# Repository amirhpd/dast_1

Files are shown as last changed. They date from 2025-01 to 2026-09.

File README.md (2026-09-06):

# DAST-1

A serial manipulator: 3D-printed mechanics, hobby servos, an Arduino Nano 33 BLE Sense Rev2,
and a ROS 2 stack with MoveIt 2 motion planning and a Gazebo simulation.
The hardware has 5 joints; the simulated robot has a sixth, `joint_6`, a wrist rotation with no
servo behind it.

## Hardware

* Mechanical parts are 3D printed — printable STLs and drawings are in [`Mechanics/`](Mechanics),
  and the coordinate frames are shown in [`frames.pdf`](frames.pdf)
* 5 × MG996R servos, one per joint
* Controller: Arduino Nano 33 BLE Sense Rev2, connected over USB
* Firmware is in a separate project: [dast_1_emb](https://github.com/amirhpd/dast_1_emb)
* Xbox 360 Kinect (model 1414) for depth sensing — see [Kinect](#kinect) below

## Requirements

* Ubuntu 26.04 LTS with ROS 2 Lyrical Luth (Gazebo Jetty)

## Set up on a new machine

Everything needed to stand up a fresh machine lives in
[`system_mirroring/`](system_mirroring). Pick whichever route suits you.

### By hand

Four scripts, in order, then build:

```bash
git clone https://github.com/amirhpd/dast_1.git
cd dast_1/system_mirroring

./install_ros2_lyrical.sh                              # ROS 2 apt source + base system
./install_ros2_packages.sh                             # ROS/system packages + rosdep
pip install --user -r installed_python_packages.txt    # non-apt Python packages
./install_vscode_extensions.sh                         # VS Code (optional)

cd ..
source /opt/ros/lyrical/setup.bash
colcon build --cmake-args -DCMAKE_EXPORT_COMPILE_COMMANDS=ON
source install/setup.bash

./system_mirroring/verify_setup.sh                     # prints PASS/FAIL per item
```

A correct machine ends with `ALL CHECKS PASSED`.
[`system_mirroring.md`](system_mirroring/system_mirroring.md) explains each step
and the traps worth knowing about.

### With an AI agent

If you use Claude Code or a similar agent, clone the repo, open it, and paste
this prompt:

> Set this machine up to build and run the DAST-1 project.
>
> Follow `system_mirroring/system_mirroring.md` from the top. It targets Ubuntu
> 26.04 with ROS 2 Lyrical Luth — confirm the machine matches before you start,
> and stop and tell me if it does not.
>
> Run the four install scripts in order, then build the workspace with
> `colcon build --cmake-args -DCMAKE_EXPORT_COMPILE_COMMANDS=ON`, then run
> `system_mirroring/verify_setup.sh` and keep working until it reports
> `ALL CHECKS PASSED`.
>
> Notes:
> - `source /opt/ros/lyrical/setup.bash` and `source install/setup.bash` do not
>   survive between shell invocations — re-source them in every command.
> - The install scripts need `sudo` and will prompt. Tell me when you need me to
>   type a password rather than trying to work around it.
> - Finish with a headless smoke test:
>   `ros2 launch startup sim_robot.launch.py gui:=False rviz:=False`, then check
>   `ros2 control list_controllers` shows both controllers `active` and that
>   `ros2 action send_goal /task_server_angle msgs/action/TaskAction "task_number: 0"`
>   returns `success: true`. Do not open Gazebo or RViz windows.
> - Tear the sim down with a bracket pattern (`pkill -f "[g]z sim"`) — a plain
>   `pkill -f "gz sim"` also matches the shell running it.
> - Report anything you had to change from the documented steps, so I can fold it
>   back into `system_mirroring/`.

Hardware is not covered by any of the above. For the real robot, also add
yourself to the `dialout` group (`sudo usermod -aG dialout $USER`, then log out
and back in) and plug the Nano 33 into `/dev/ttyACM0`.

## Build

Once the machine is set up, a normal rebuild is:

```bash
cd dast_1
colcon build
source install/setup.bash
```

Run `source install/setup.bash` once in every new terminal. Add
`--cmake-args -DCMAKE_EXPORT_COMPILE_COMMANDS=ON` whenever you want editor
IntelliSense to pick up newly added includes.

## Run

Simulation — Gazebo, MoveIt and RViz, no hardware needed:

```bash
ros2 launch startup sim_robot.launch.py
```

Real robot — plug the Nano 33 in first (it is expected on `/dev/ttyACM0`):

```bash
ros2 launch startup run_robot.launch.py
```

Give it half a minute to settle. `ros2 control list_controllers` should show both
`joint_state_broadcaster` and `manipulator_controller` as `active`.

Everything below runs from a **second terminal**, sourced the same way
(`cd dast_1 && source install/setup.bash`).

### Moving the arm

There are two families of commands. The first plans through MoveIt: motions are checked
against obstacles and the arm takes a safe route. The second talks straight to the
controller: faster and simpler, but nothing is checked before the arm moves.

#### Through MoveIt — collision-checked

**Drag it in RViz.** In the **MotionPlanning** panel, drag the goal marker to where you
want the tip, then press *Plan & Execute*.

**Run a stored task.** Three canned poses ship with the project, numbered 0, 1 and 2:

```bash
ros2 action send_goal /task_server_angle msgs/action/TaskAction "task_number: 1"
```

**Set the joint angles** — five values, in **degrees**, one per joint:

```bash
ros2 run moveit interface_angle 20 30 -15 40 10
```

**Set the tip pose** — `x y z roll pitch yaw`, in **metres and radians**:

```bash
ros2 run moveit interface_pose 1.173 -3.223 6.196 0.953 -0.143 0.450
```

Not every pose is reachable; see *Reachable workspace* below. To find a valid one, move the
arm with `interface_angle` and read the tip off `ros2 run tf2_ros tf2_echo world tip`.

**Follow a trajectory of several waypoints.** The waypoints live in a YAML file, and the
whole path is planned segment by segment:

```bash
ros2 run moveit interface_sequence src/moveit/config/sequence_example.yaml
```

Copy `src/moveit/config/sequence_example.yaml` and edit its `segments:` list to make your
own path. Each segment takes either `joints:` (radians) or `pose:`, and the file's comments
explain the rest. Leave `blend_radius: 0` — corner-rounding needs a 6-DOF arm and DAST-1
has 5, so any other value fails the whole sequence.

#### Straight to the controller — no collision checking

These bypass MoveIt entirely. Nothing stops the arm driving through an obstacle, or through
itself, so keep the workspace clear.

**Send one trajectory and forget it.** Positions are in **radians**, in `joint_names` order:

```bash
ros2 topic pub --once /manipulator_controller/joint_trajectory trajectory_msgs/msg/JointTrajectory \
'{joint_names: [joint_1, joint_2, joint_3, joint_4, joint_5],
  points: [{positions: [0.3, 0.4, -0.2, 0.5, 0.1], time_from_start: {sec: 3}}]}'
```

**Send it and wait for the result.** Same thing as an action, so you get success or failure
back, and `--feedback` will stream progress while it runs:

```bash
ros2 action send_goal /manipulator_controller/follow_joint_trajectory \
  control_msgs/action/FollowJointTrajectory \
'{trajectory: {joint_names: [joint_1, joint_2, joint_3, joint_4, joint_5],
  points: [{positions: [0.4, 0.2, 0.3, 0.5, 0.0], time_from_start: {sec: 2}},
           {positions: [-0.4, 0.6, 0.1, 1.0, 0.2], time_from_start: {sec: 5}}]}}'
```

`time_from_start` counts from the beginning of the trajectory, so each waypoint's value must
be larger than the one before it.

### Reachable workspace

All joints are limited to ±90°, and not every pose in that range can be reached.
The scan sweeps `joint_1`..`joint_5` with `joint_6` held at 0, so it understates the
reachable workspace of the 6-DOF description.
`points.pcd` holds the measured reachable workspace:

```bash
ros2 run moveit publish_pointcloud.py     # run from the repository root
```

It publishes to `/point_cloud`; add a **PointCloud2** display in RViz to see it.

## Kinect

An Xbox 360 Kinect (model 1414) provides colour and depth. It is driven by the `kinect`
package, which is **standalone**: it is not started by `sim_robot.launch.py` or
`run_robot.launch.py`, and nothing in the robot stack depends on it yet.

It needs its 12 V power brick as well as USB. On USB alone only the motor enumerates and the
LED blinks green — `lsusb | grep 045e` must list all three of `02b0` (motor), `02ad` (audio)
and `02ae` (camera).

```bash
ros2 launch kinect kinect.launch.py              # driver + static TF
ros2 launch kinect kinect.launch.py rviz:=True   # ...and RViz, preconfigured
```

| topic | type | contents |
| --- | --- | --- |
| `/kinect/rgb/image_raw` | `sensor_msgs/Image` | `rgb8`, 640×480, 30 Hz |
| `/kinect/depth/image_raw` | `sensor_msgs/Image` | `16UC1`, millimetres, 0 where nothing was seen |
| `/kinect/points` | `sensor_msgs/PointCloud2` | organised XYZRGB, one point per pixel |
| `/kinect/rgb/camera_info`, `/kinect/depth/camera_info` | `sensor_msgs/CameraInfo` | the calibration below |

Depth is captured as `FREENECT_DEPTH_REGISTERED`, so it is already aligned to the colour image
and one calibration covers both. The point cloud is only built while something is subscribed to
it — it is about 4.9 MB per frame.

### Calibration

The measured intrinsics for this unit live in
[`src/kinect/config/kinect_rgb.yaml`](src/kinect/config/kinect_rgb.yaml) and are loaded at
startup through the `camera_info_url` parameter
(default `package://kinect/config/kinect_rgb.yaml`). Editing that file and restarting is
enough — no rebuild. If the file is missing or is not 640×480, the node warns and falls back to
nominal Kinect v1 values, and the cloud becomes approximate.

| | |
| --- | --- |
| fx, fy | 549.996, 552.698 |
| cx, cy | 316.370, 269.456 |
| distortion (`plumb_bob`) | 0.168766, −0.361444, 0.002809, −0.002889, 0 |

Distortion is corrected when the cloud is built, through a per-pixel lookup table computed once
at startup. It is not a small effect: at 1 m depth it moves a corner pixel by about 4 cm.

To redo the calibration — 8×6 interior corners, 25 mm squares:

```bash
ros2 launch kinect kinect.launch.py
ros2 run camera_calibration cameracalibrator --size 8x6 --square 0.025 \
  --no-service-check --ros-args \
  -r image:=/kinect/rgb/image_raw -r camera:=/kinect/rgb
```

Two upstream bugs in `camera_calibration` 7.1.7 have to be patched first, or it crashes on
startup and again on SAVE. Both are one-line fixes to installed files, and an `apt upgrade`
silently reverts them:

```bash
sudo sed -i 's/self\.get_logger()\.warn(/self.get_logger().warning(/' \
  /opt/ros/lyrical/lib/python3.14/site-packages/camera_calibration/camera_calibrator.py
sudo sed -i 's/\.tostring()/.tobytes()/' \
  /opt/ros/lyrical/lib/python3.14/site-packages/camera_calibration/mono_calibrator.py \
  /opt/ros/lyrical/lib/python3.14/site-packages/camera_calibration/stereo_calibrator.py
```

### Where to bolt it

Two measured limits decide the mounting position.

**Minimum range is about 50 cm.** The closest reading over 900 frames was 502 mm, and nothing
nearer than that exists. Anything closer is reported as 0, which becomes a *hole* in the point
cloud — and a hole reads as empty space to MoveIt, not as an obstacle. Mount the camera so the
whole arm workspace stays beyond roughly 60 cm.

**The field of view is 60.4° × 46.9°**, computed from the intrinsics above:

| distance | area covered |
| --- | --- |
| 0.6 m | 0.70 × 0.52 m |
| 1.0 m | 1.16 × 0.87 m |
| 1.5 m | 1.75 × 1.30 m |
| 2.0 m | 2.33 × 1.74 m |

The arm reaches about 0.71 m (`points.pcd` measures 7.14 model units, and the model is in
decimetres — see *Units* below), so an eye-to-hand mount around 1 m back covers the workspace and
stays clear of the 50 cm floor. The current mount is 1.03 m from `base_link`.

Depth noise, measured as the per-pixel standard deviation over 30 s:

| range | median σ | 95th percentile |
| --- | --- | --- |
| 0.5–0.7 m | 0.5 mm | 0.7 mm |
| 0.9–1.1 m | 1.4 mm | 2.2 mm |
| 1.4–1.8 m | 2.8 mm | 4.6 mm |

A 1 cm octomap voxel is therefore comfortable out to about 2 m. Over the same 30 s the driver
delivered 899 frames at 29.97 Hz with no drops, and the Kinect had its internal USB hub to
itself; the Nano's serial traffic is negligible beside it.

**Tilt.** The Kinect's motorised base holds whatever angle it was last commanded to, and forgets
it when the 12 V drops. The driver therefore commands the tilt on every start, so it is the same
angle every run rather than whatever someone last left it at:

```bash
ros2 launch kinect kinect.launch.py tilt_degrees:=-16   # -30..30, negative is head down
```

The default is **−16°**, matching the current mount. After moving the motor the node reads the
angle back from the accelerometer and warns if it does not match what was commanded — a stalled
motor is otherwise invisible. Set `set_tilt:=False` to leave the motor untouched.

> The tilt must match the angle the camera-to-`base_link` transform was measured at. Change
> `tilt_degrees` and every extrinsic is silently wrong, with nothing to show for it but a point
> cloud that no longer lines up with the robot. Repeatability is about 1°, so bake the nominal
> tilt into the URDF as well.

### In the robot

The camera is part of the robot description, so both modes publish the same topics and the
planner sees the same obstacles:

| | simulation | real robot |
| --- | --- | --- |
| source | Gazebo `rgbd_camera` + `ros_gz_bridge` | `kinect_node` |
| started by | `sim_robot.launch.py` | `run_robot.launch.py` |
| `/kinect/points` | ✔ | ✔ |
| `/kinect/rgb/image_raw` | ✔ | ✔ |
| `/kinect/depth/image_raw` | `32FC1`, model units | `16UC1`, millimetres |
| `/kinect/depth/camera_info` | — | ✔ |
| cloud `frame_id` | `kinect_link` (x forward) | `kinect_rgb_optical_frame` (z forward) |

The last two rows are the only differences. Gazebo emits its cloud along the sensor link's **x**
axis and `gz_frame_id` only labels the message rather than rotating it, so the simulated cloud is
published in `kinect_link` and the real one in the optical frame. Both are correct in their own
frame and TF reconciles them, so RViz and MoveIt behave identically — but code that hardcodes a
frame name instead of asking TF will only work in one mode.

The mount pose lives in `description.urdf.xacro` as `kinect_xyz` / `kinect_rpy`, and
`sensors_3d.yaml` feeds `/kinect/points` to MoveIt's octomap at a 1 cm voxel.

Gazebo needs `worlds/dast_1.sdf` rather than its stock `empty.sdf`: the stock world does not load
`gz-sim-sensors-system`, and without it the camera is created and advertises every topic but
never renders a frame, silently.

### Units

**The robot model is in decimetres, not metres.** The meshes are millimetres scaled by `0.01`, so
one unit in the URDF is 10 cm: the 8 cm printed base is `0.8`, the 0.71 m reach is `7.14`, and
`points.pcd` spans ±5.8. Every length in the URDF, `sensors_3d.yaml` and the Gazebo sensor
follows that convention.

The Kinect does not. Its driver publishes true metres, so `run_robot.launch.py` passes
`point_scale: 10.0` to convert the cloud into model units. Simulation needs no such conversion —
Gazebo already works in whatever units the URDF uses.

This is worth fixing properly one day, by scaling the meshes at `0.001` and dividing every joint
origin by ten. That would also invalidate every recorded pose, `points.pcd` and the waypoint
YAMLs, so it is deliberately not done here.

### Checking the sensor

Depth and geometry come from different places, so they fail differently:

* `z` comes straight from the Kinect's own factory depth calibration and is passed through
  untouched. Check it against a tape measure on a flat wall. Expect a 1–2 cm offset, because the
  depth origin sits inside the housing rather than at the front glass — measure at two distances
  and compare the *difference*, which cancels the offset.
* `x` and `y` come from the intrinsics above. Check them against a known width: hold a ruler
  flat, facing the camera, add a **PointCloud2** display in RViz, pick the **Select** tool, box
  a few points at each end, and read `Position → x` under each point in the **Selection** panel.
  Values are in metres. Expand the `Point ...` rows — the number in the row itself is only an
  index.

## License

This project is licensed under the GPLv3 License.

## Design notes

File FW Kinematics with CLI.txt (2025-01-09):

FW kinematics:

ros2 launch description display.launch.py

ros2 topic list 
gives: /tf which is dynamic transformation and /tf_static which is static transformation

ros2 topic info /tf --verbose
we see that robot_state_publisher node is publishing to /tf

ros2 topic eccho /tf
it constantly publishes the msgs that define the position of each frame relative to the previous frame

ros2 run tf2_tools view_frames
generates a graph of the frames and their connections

ros2 run tf2_ros tf2_echo world tip
gives translation and rotation values of between the given frames
if the first and last frames are passed, it actually solves the fw kinematics problem

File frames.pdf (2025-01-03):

view_frames Result

Recorded at time: 1735861924.2365034

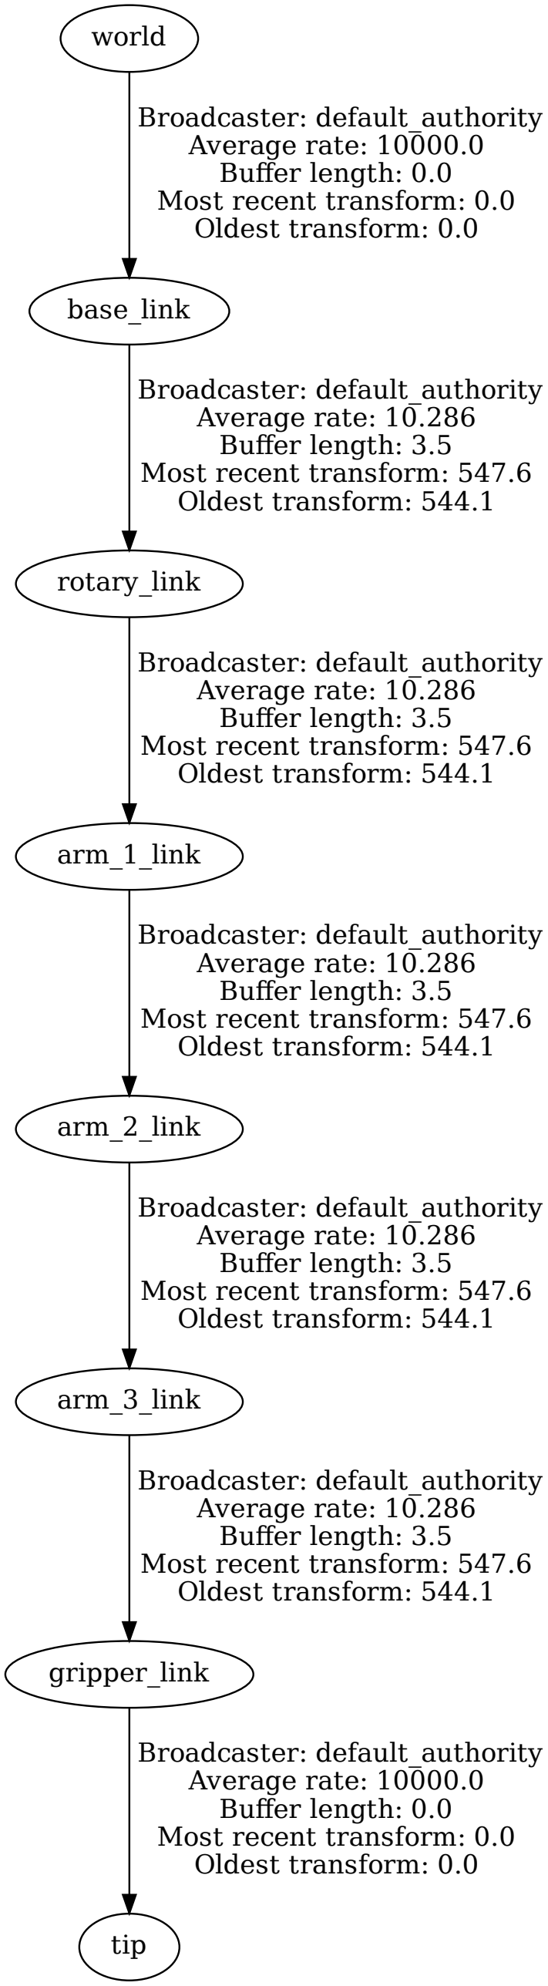
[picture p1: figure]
world; base_link; Broadcaster: default_authority Average rate: 10000.0 Buffer length: 0.0 Most recent transform: 0.0 Oldest transform: 0.0; rotary_link; Broadcaster: default_authority Average rate: 10.286 Buffer length: 3.5 Most recent transform: 547.6 Oldest transform: 544.1; gripper_link; tip; arm_3_link; arm_1_link; arm_2_link

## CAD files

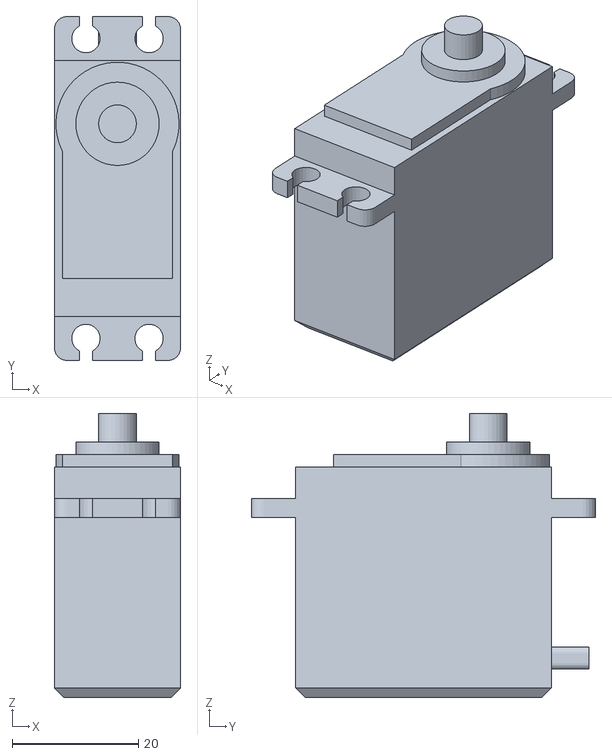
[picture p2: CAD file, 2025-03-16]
Mechanics/ARM-1/servo_mg996r.stl
20.0 x 54.5 x 45.0

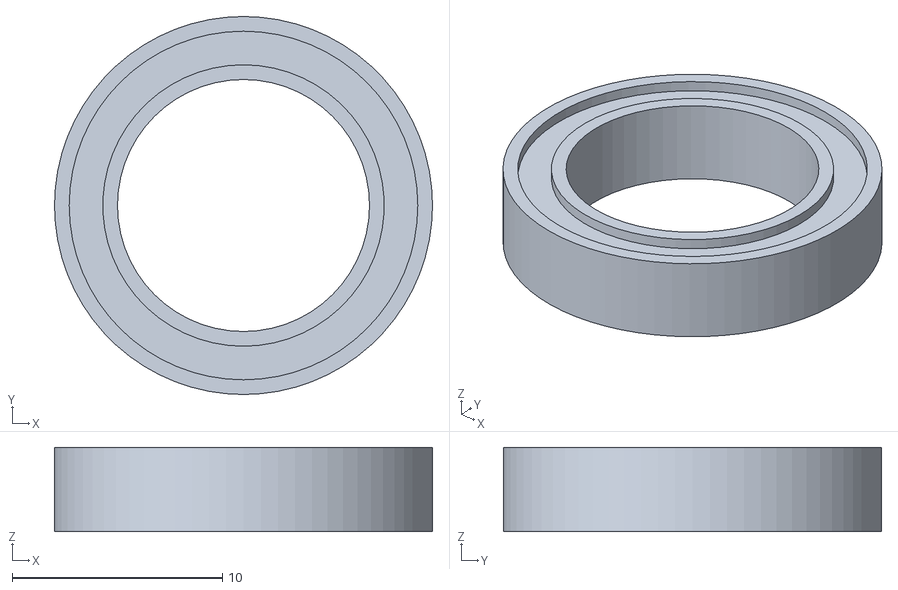
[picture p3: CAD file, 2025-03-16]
Mechanics/BASE/bearing_18_12_4.stl
18.0 x 18.0 x 4.00

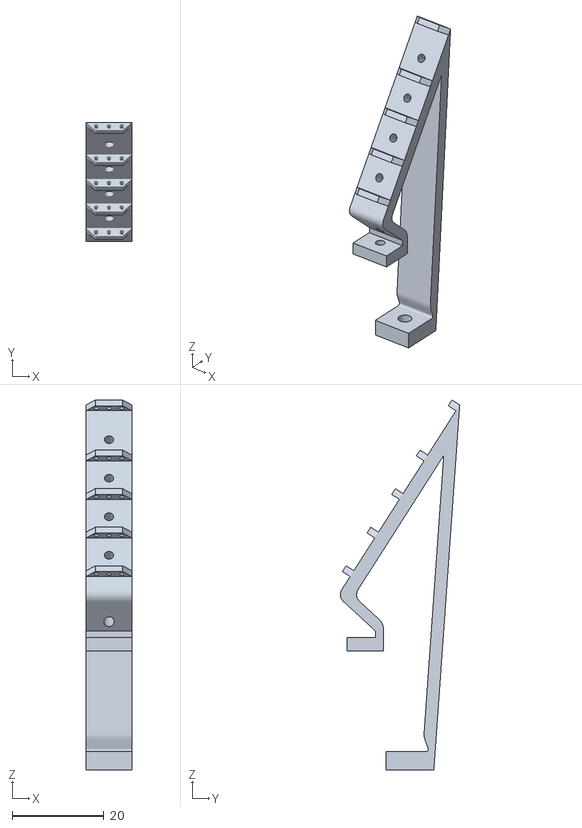
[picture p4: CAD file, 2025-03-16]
Mechanics/GRIPPER/finger_8.stl
10.00 x 26.1 x 80.9

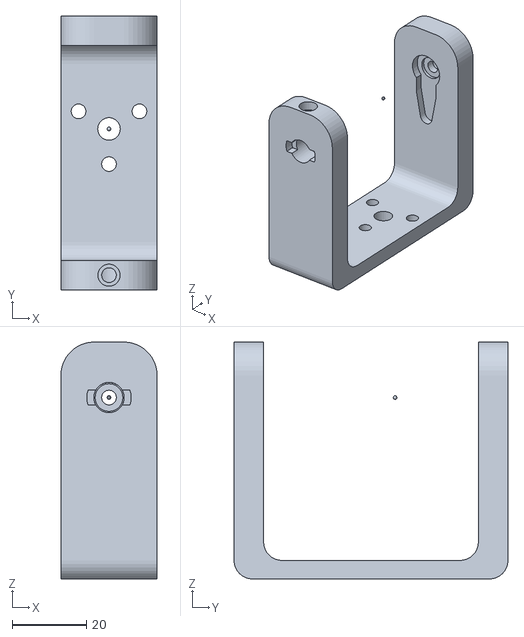
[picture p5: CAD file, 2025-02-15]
src/description/meshes/rotary.stl
26.0 x 74.0 x 64.0

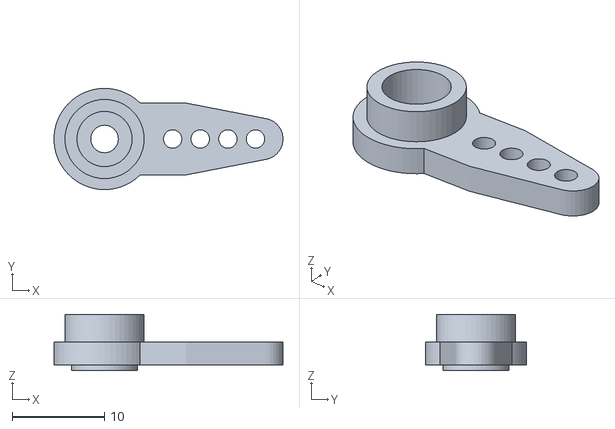
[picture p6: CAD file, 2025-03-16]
Mechanics/ARM-1/servo_connector_3.stl
24.9 x 11.0 x 6.10

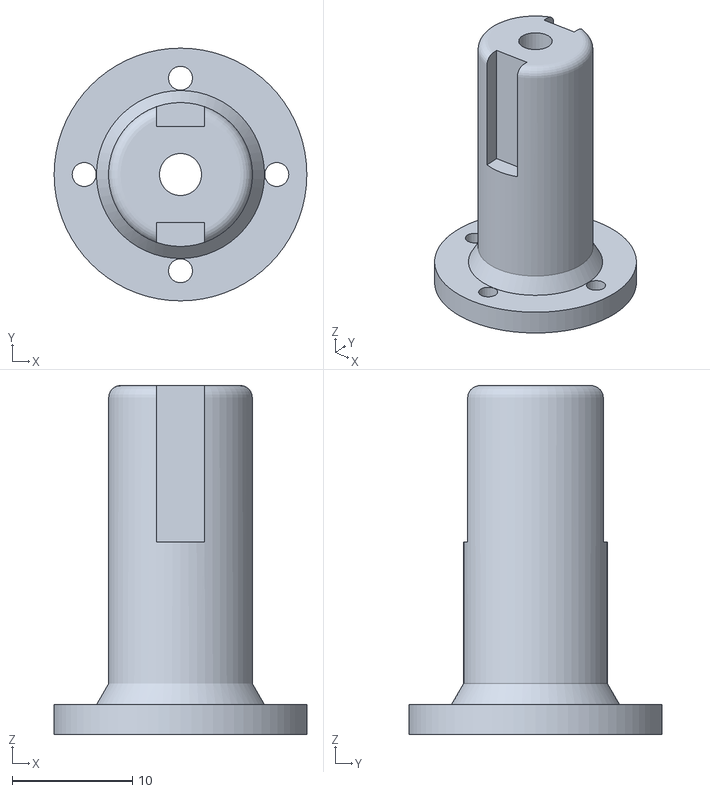
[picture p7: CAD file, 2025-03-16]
Mechanics/ARM-3/joint_5_shaft.stl
21.0 x 21.0 x 29.0

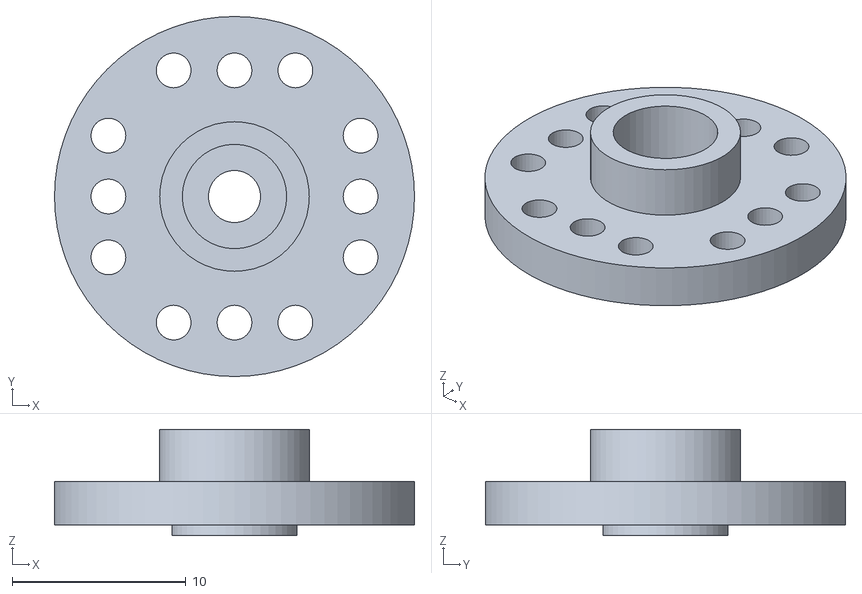
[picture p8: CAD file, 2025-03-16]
Mechanics/BASE/servo_connector_1.stl
20.7 x 20.7 x 6.10

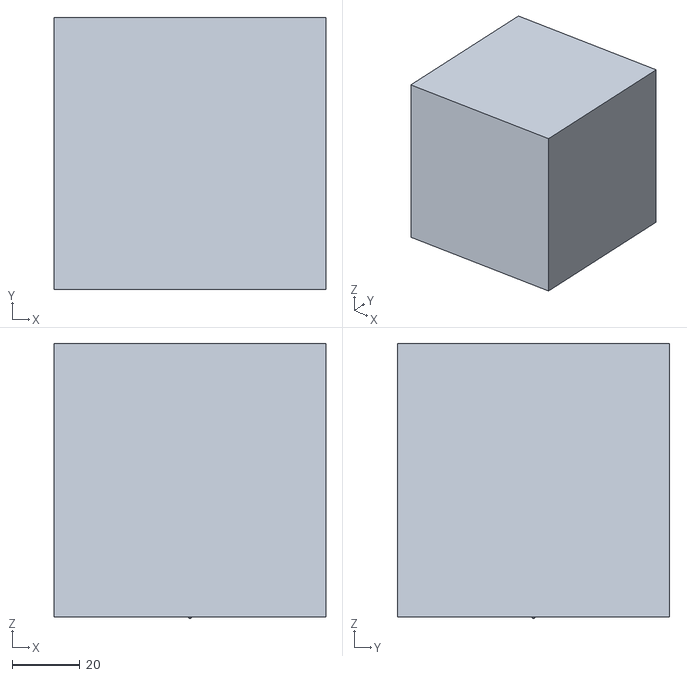
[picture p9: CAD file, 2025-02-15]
src/description/meshes/base_collision.stl
80.5 x 80.5 x 81.5

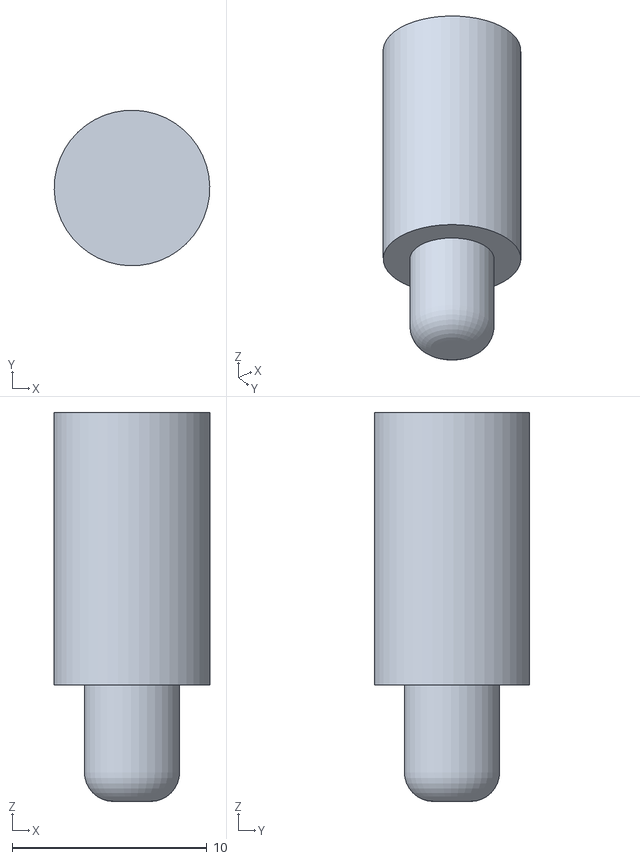
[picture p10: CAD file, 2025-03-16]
Mechanics/ARM-1/bearing_shaft.stl
8.00 x 7.99 x 20.0

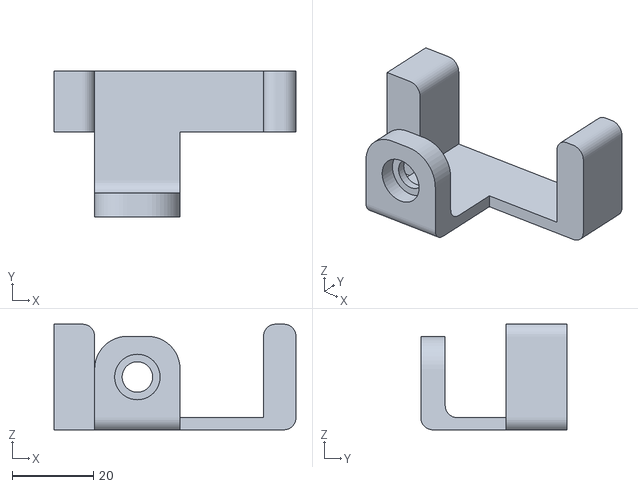
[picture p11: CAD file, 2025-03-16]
Mechanics/ARM-3/arm_3_body.stl
59.5 x 36.0 x 26.0

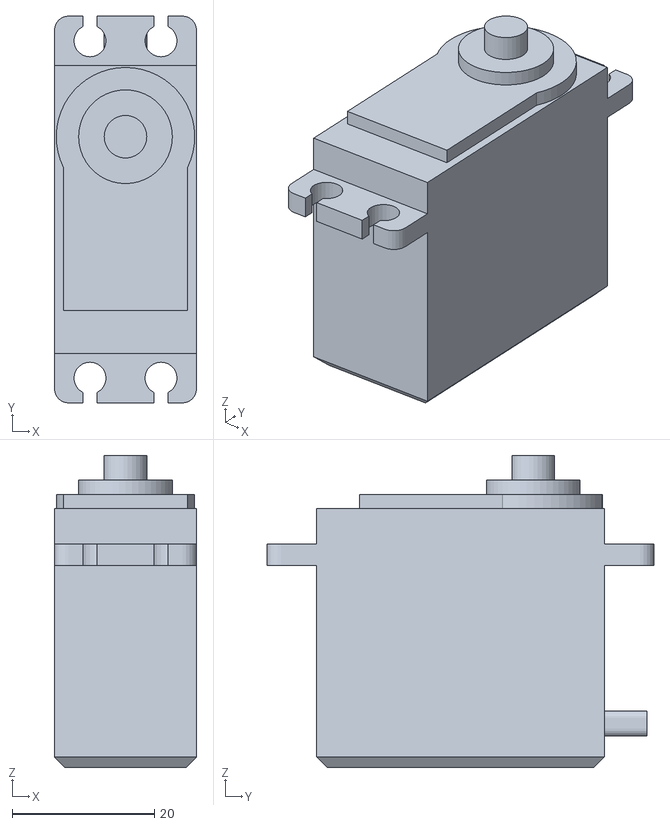
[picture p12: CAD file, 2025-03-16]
Mechanics/BASE/servo_mg996r.stl
20.0 x 54.5 x 44.0

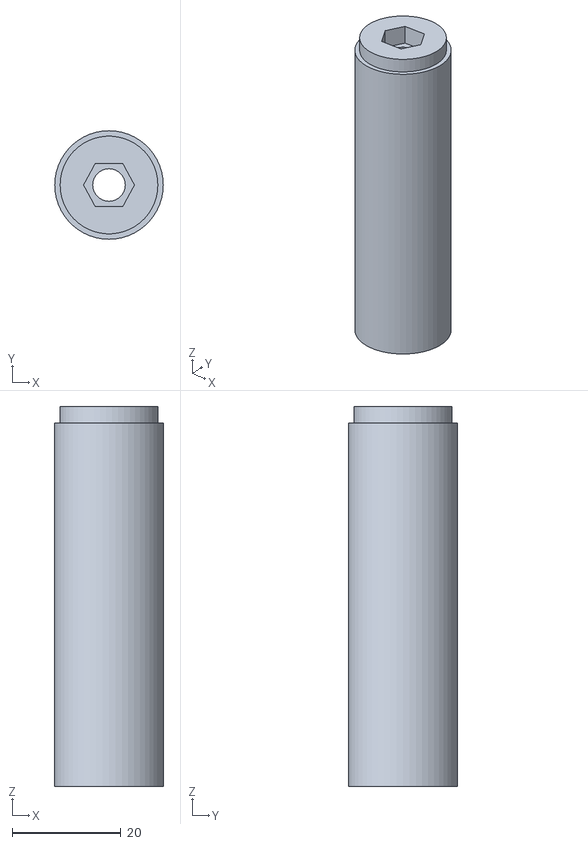
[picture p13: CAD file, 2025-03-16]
Mechanics/GRIPPER/motor_hold.stl
20.0 x 20.0 x 70.0

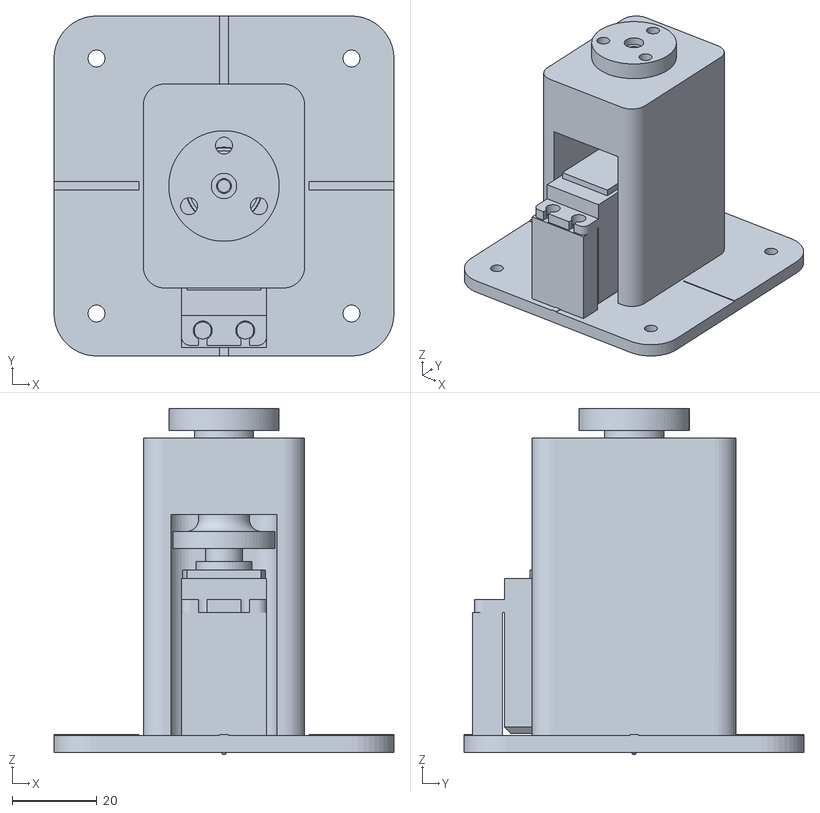
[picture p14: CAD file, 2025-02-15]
src/description/meshes/base.stl
80.0 x 80.0 x 81.5

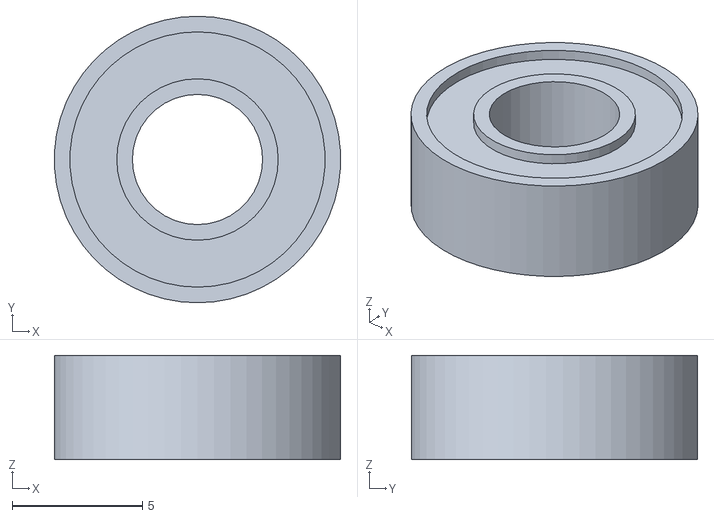
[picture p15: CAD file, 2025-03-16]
Mechanics/ARM-1/bearing_11_5_4.stl
11.0 x 11.0 x 4.00

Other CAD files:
Mechanics/ARM-2/joint_2_housing.stl
Mechanics/ARM-1/arm_1_body.stl
Mechanics/ARM-1/joint_1_housing.stl
Mechanics/ARM-2/arm_2_body.stl
Mechanics/ARM-3/joint_3_housing.stl
Mechanics/ARM-3/joint_5_body.stl
Mechanics/BASE/housing.stl
Mechanics/BASE/plate.stl
Mechanics/BASE/shaft.stl
Mechanics/BASE/shaft_hold.stl
Mechanics/GRIPPER/body.stl
Mechanics/GRIPPER/bolt_cap.stl
Mechanics/GRIPPER/coupling.stl
Mechanics/GRIPPER/motor_1.stl
Mechanics/GRIPPER/screw.stl
Mechanics/GRIPPER/screw_head.stl
src/description/meshes/arm_1.stl
src/description/meshes/arm_1_collision.stl
src/description/meshes/arm_2.stl
src/description/meshes/arm_2_collision.stl
src/description/meshes/arm_3.stl
src/description/meshes/arm_3_collision.stl
src/description/meshes/gripper_3.stl
src/description/meshes/gripper_3_collision.stl
src/description/meshes/rotary_collision.stl

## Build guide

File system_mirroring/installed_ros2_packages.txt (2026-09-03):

libserial-dev
ros-dev-tools
ros-lyrical-desktop
ros-lyrical-gz-ros2-control
ros-lyrical-joint-state-publisher-gui
ros-lyrical-moveit
ros-lyrical-moveit-planners
ros-lyrical-pcl-conversions
ros-lyrical-pcl-ros
ros-lyrical-ros2-control
ros-lyrical-ros2-controllers
ros-lyrical-ros-gz-bridge
ros-lyrical-ros-gz-sim
ros-lyrical-xacro

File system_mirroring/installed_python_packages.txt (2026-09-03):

# Python packages the project needs that do NOT come from apt.
#
# Everything else it imports -- numpy, pyserial, and all rclpy/launch/moveit
# modules -- arrives with the ros-lyrical-* apt packages. Do NOT pip-install
# ROS Python modules; they must match the apt build exactly.
#
# Ubuntu 26.04 is an externally-managed Python environment (PEP 668), so pip
# needs --user (or a venv). Install with:
#     pip install --user -r installed_python_packages.txt

pypcd4>=1.4.3

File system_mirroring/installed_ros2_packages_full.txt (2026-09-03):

ros-lyrical-ackermann-msgs=2.0.2-7resolute.20260811.214511
ros-lyrical-ackermann-steering-controller=6.9.0-1resolute.20260813.022148
ros-lyrical-action-msgs=2.4.5-1resolute.20260811.210253
ros-lyrical-action-tutorials-cpp=0.37.9-1resolute.20260812.021114
ros-lyrical-action-tutorials-py=0.37.9-1resolute.20260812.021218
ros-lyrical-actuator-msgs=0.0.1-5resolute.20260811.214520
ros-lyrical-admittance-controller=6.9.0-1resolute.20260813.021833
ros-lyrical-ament-cmake=2.8.8-1resolute.20260728.175713
ros-lyrical-ament-cmake-auto=2.8.8-1resolute.20260728.210738
ros-lyrical-ament-cmake-copyright=0.20.6-1resolute.20260728.204014
ros-lyrical-ament-cmake-core=2.8.8-1resolute.20260728.162608
ros-lyrical-ament-cmake-cppcheck=0.20.6-1resolute.20260728.204151
ros-lyrical-ament-cmake-cpplint=0.20.6-1resolute.20260728.204159
ros-lyrical-ament-cmake-export-definitions=2.8.8-1resolute.20260728.173325
ros-lyrical-ament-cmake-export-dependencies=2.8.8-1resolute.20260728.173500
ros-lyrical-ament-cmake-export-include-directories=2.8.8-1resolute.20260728.172444
ros-lyrical-ament-cmake-export-libraries=2.8.8-1resolute.20260728.173328
ros-lyrical-ament-cmake-export-link-flags=2.8.8-1resolute.20260728.173334
ros-lyrical-ament-cmake-export-targets=2.8.8-1resolute.20260728.173432
ros-lyrical-ament-cmake-flake8=0.20.6-1resolute.20260728.204007
ros-lyrical-ament-cmake-gen-version-h=2.8.8-1resolute.20260728.173325
ros-lyrical-ament-cmake-gmock=2.8.8-1resolute.20260728.175747
ros-lyrical-ament-cmake-gtest=2.8.8-1resolute.20260728.175609
ros-lyrical-ament-cmake-include-directories=2.8.8-1resolute.20260728.173227
ros-lyrical-ament-cmake-libraries=2.8.8-1resolute.20260728.173352
ros-lyrical-ament-cmake-lint-cmake=0.20.6-1resolute.20260728.204241
ros-lyrical-ament-cmake-mypy=0.20.6-1resolute.20260728.204152
ros-lyrical-ament-cmake-pep257=0.20.6-1resolute.20260728.204012
ros-lyrical-ament-cmake-pytest=2.8.8-1resolute.20260728.175653
ros-lyrical-ament-cmake-python=2.8.8-1resolute.20260728.173021
ros-lyrical-ament-cmake-ros=0.15.8-1resolute.20260812.003148
ros-lyrical-ament-cmake-ros-core=0.15.8-1resolute.20260728.173607
ros-lyrical-ament-cmake-target-dependencies=2.8.8-1resolute.20260728.173503
ros-lyrical-ament-cmake-test=2.8.8-1resolute.20260728.175319
ros-lyrical-ament-cmake-uncrustify=0.20.6-1resolute.20260728.210813
ros-lyrical-ament-cmake-version=2.8.8-1resolute.20260728.173013
ros-lyrical-ament-cmake-xmllint=0.20.6-1resolute.20260728.204019
ros-lyrical-ament-copyright=0.20.6-1resolute.20260728.172704
ros-lyrical-ament-cppcheck=0.20.6-1resolute.20260728.173125
ros-lyrical-ament-cpplint=0.20.6-1resolute.20260728.173508
ros-lyrical-ament-flake8=0.20.6-1resolute.20260728.172702
ros-lyrical-ament-index-cpp=1.13.3-3resolute.20260728.204744
ros-lyrical-ament-index-python=1.13.3-3resolute.20260728.172618
ros-lyrical-ament-lint=0.20.6-1resolute.20260728.172451
ros-lyrical-ament-lint-auto=0.20.6-1resolute.20260728.204247
ros-lyrical-ament-lint-cmake=0.20.6-1resolute.20260728.173508
ros-lyrical-ament-lint-common=0.20.6-1resolute.20260728.211054
ros-lyrical-ament-mypy=0.20.6-1resolute.20260728.173532
ros-lyrical-ament-package=0.18.3-3resolute.20260430.010336
ros-lyrical-ament-pep257=0.20.6-1resolute.20260728.172706
ros-lyrical-ament-uncrustify=0.20.6-1resolute.20260728.210701
ros-lyrical-ament-xmllint=0.20.6-1resolute.20260728.172708
ros-lyrical-angles=1.16.1-3resolute.20260728.204755
ros-lyrical-backward-ros=1.0.8-5resolute.20260728.173605
ros-lyrical-battery-state-broadcaster=6.9.0-1resolute.20260813.021523
ros-lyrical-bicycle-steering-controller=6.9.0-1resolute.20260813.022055
ros-lyrical-builtin-interfaces=2.4.5-1resolute.20260811.194455
ros-lyrical-chained-filter-controller=6.9.0-1resolute.20260813.021545
ros-lyrical-chomp-motion-planner=2.15.0-1resolute.20260814.183552
ros-lyrical-class-loader=2.9.4-3resolute.20260728.211940
ros-lyrical-common-interfaces=5.9.3-1resolute.20260811.235041
ros-lyrical-composition=0.37.9-1resolute.20260812.024540
ros-lyrical-composition-interfaces=2.4.5-1resolute.20260811.235637
ros-lyrical-console-bridge-vendor=1.9.1-3resolute.20260728.205113
ros-lyrical-controller-interface=6.9.0-1resolute.20260812.031044
ros-lyrical-controller-manager=6.9.0-1resolute.20260812.031837
ros-lyrical-controller-manager-msgs=6.9.0-1resolute.20260811.235011
ros-lyrical-control-msgs=6.10.0-1resolute.20260812.000019
ros-lyrical-control-toolbox=6.4.0-1resolute.20260813.020756
ros-lyrical-cv-bridge=4.1.0-3resolute.20260812.021420
ros-lyrical-demo-nodes-cpp=0.37.9-1resolute.20260812.024338
ros-lyrical-demo-nodes-cpp-native=0.37.9-1resolute.20260812.021113
ros-lyrical-demo-nodes-py=0.37.9-1resolute.20260812.023921
ros-lyrical-depthimage-to-laserscan=2.5.1-4resolute.20260812.021437
ros-lyrical-desktop=0.13.0-3resolute.20260812.081153
ros-lyrical-diagnostic-msgs=5.9.3-1resolute.20260811.231430
ros-lyrical-diagnostic-updater=4.4.7-1resolute.20260812.015047
ros-lyrical-diff-drive-controller=6.9.0-1resolute.20260813.021810
ros-lyrical-dummy-map-server=0.37.9-1resolute.20260812.021337
ros-lyrical-dummy-robot-bringup=0.37.9-1resolute.20260812.080900
ros-lyrical-dummy-sensors=0.37.9-1resolute.20260812.021451
ros-lyrical-eigen3-cmake-module=0.5.1-3resolute.20260728.205221
ros-lyrical-eigen-stl-containers=1.1.0-3resolute.20260728.205309
ros-lyrical-example-interfaces=0.14.1-3resolute.20260811.214647
ros-lyrical-examples-rclcpp-minimal-action-client=0.21.5-3resolute.20260812.021115
ros-lyrical-examples-rclcpp-minimal-action-server=0.21.5-3resolute.20260812.021127
ros-lyrical-examples-rclcpp-minimal-client=0.21.5-3resolute.20260812.021143
ros-lyrical-examples-rclcpp-minimal-composition=0.21.5-3resolute.20260812.015758
ros-lyrical-examples-rclcpp-minimal-publisher=0.21.5-3resolute.20260812.015042
ros-lyrical-examples-rclcpp-minimal-service=0.21.5-3resolute.20260812.021144
ros-lyrical-examples-rclcpp-minimal-subscriber=0.21.5-3resolute.20260812.015803
ros-lyrical-examples-rclcpp-minimal-timer=0.21.5-3resolute.20260812.023244
ros-lyrical-examples-rclcpp-multithreaded-executor=0.21.5-3resolute.20260812.015114
ros-lyrical-examples-rclpy-executors=0.21.5-3resolute.20260812.023800
ros-lyrical-examples-rclpy-minimal-action-client=0.21.5-3resolute.20260812.023832
ros-lyrical-examples-rclpy-minimal-action-server=0.21.5-3resolute.20260812.021220
ros-lyrical-examples-rclpy-minimal-client=0.21.5-3resolute.20260812.023835
ros-lyrical-examples-rclpy-minimal-publisher=0.21.5-3resolute.20260812.024013
ros-lyrical-examples-rclpy-minimal-service=0.21.5-3resolute.20260812.024002
ros-lyrical-examples-rclpy-minimal-subscriber=0.21.5-3resolute.20260812.024040
ros-lyrical-fastcdr=2.3.6-1resolute.20260728.172850
ros-lyrical-fastdds=3.6.2-1resolute.20260728.174239
ros-lyrical-filters=2.2.2-3resolute.20260812.023251
ros-lyrical-foonathan-memory-vendor=1.4.1-1resolute.20260728.173726
ros-lyrical-force-torque-sensor-broadcaster=6.9.0-1resolute.20260813.020931
ros-lyrical-forward-command-controller=6.9.0-1resolute.20260813.021543
ros-lyrical-generate-parameter-library=1.3.0-1resolute.20260812.024534
ros-lyrical-generate-parameter-library-py=1.3.0-1resolute.20260728.174510
ros-lyrical-geometric-shapes=2.3.4-1resolute.20260812.014934
ros-lyrical-geometry2=0.45.9-1resolute.20260812.065932
ros-lyrical-geometry-msgs=5.9.3-1resolute.20260811.214840
ros-lyrical-google-benchmark-vendor=0.7.0-3resolute.20260728.170214
ros-lyrical-gpio-controllers=6.9.0-1resolute.20260813.020932
ros-lyrical-gps-msgs=3.1.1-1resolute.20260817.165952
ros-lyrical-gps-sensor-broadcaster=6.9.0-1resolute.20260813.021543
ros-lyrical-gz-cmake-vendor=0.4.5-1resolute.20260728.204248
ros-lyrical-gz-common-vendor=0.3.6-1resolute.20260728.211925
ros-lyrical-gz-dartsim-vendor=0.1.3-3resolute.20260728.205412
ros-lyrical-gz-fuel-tools-vendor=0.3.1-3resolute.20260728.213226
ros-lyrical-gz-gui-vendor=0.3.1-3resolute.20260729.165027
ros-lyrical-gz-math-vendor=0.4.4-1resolute.20260728.210836
ros-lyrical-gz-msgs-vendor=0.3.4-2resolute.20260728.211937
ros-lyrical-gz-ogre-next-vendor=0.2.1-1resolute.20260728.205418
ros-lyrical-gz-physics-vendor=0.4.5-1resolute.20260728.230022
ros-lyrical-gz-plugin-vendor=0.3.1-3resolute.20260728.210826
ros-lyrical-gz-rendering-vendor=0.4.4-1resolute.20260729.162653
ros-lyrical-gz-ros2-control=3.0.8-1resolute.20260812.033512
ros-lyrical-gz-sensors-vendor=0.3.3-1resolute.20260729.170045
ros-lyrical-gz-sim-vendor=0.4.6-1resolute.20260810.125655
ros-lyrical-gz-tools-vendor=0.2.1-3resolute.20260728.204537
ros-lyrical-gz-transport-vendor=0.3.5-1resolute.20260728.213714
ros-lyrical-gz-utils-vendor=0.4.1-3resolute.20260728.210531
ros-lyrical-hardware-interface=6.9.0-1resolute.20260812.025059
ros-lyrical-image-geometry=4.1.0-3resolute.20260812.010916
ros-lyrical-image-tools=0.37.9-1resolute.20260812.015825
ros-lyrical-image-transport=6.4.10-1resolute.20260812.021512
ros-lyrical-imu-sensor-broadcaster=6.9.0-1resolute.20260813.020929
ros-lyrical-interactive-markers=2.8.4-1resolute.20260812.025722
ros-lyrical-intra-process-demo=0.37.9-1resolute.20260812.020838
ros-lyrical-joint-limits=6.9.0-1resolute.20260812.024530
ros-lyrical-joint-state-broadcaster=6.9.0-1resolute.20260813.021535
ros-lyrical-joint-state-publisher=2.4.3-1resolute.20260812.024103
ros-lyrical-joint-state-publisher-gui=2.4.3-1resolute.20260812.024521
ros-lyrical-joint-trajectory-controller=6.9.0-1resolute.20260813.021739
ros-lyrical-joy=3.3.0-4resolute.20260812.021518
ros-lyrical-kdl-parser=3.0.1-3resolute.20260812.012108
ros-lyrical-keyboard-handler=0.5.1-1resolute.20260728.205547
ros-lyrical-kinematics-interface=2.4.2-1resolute.20260812.023544
ros-lyrical-laser-geometry=2.11.3-6resolute.20260812.065336
ros-lyrical-launch=3.9.8-1resolute.20260728.172811
ros-lyrical-launch-param-builder=0.1.1-5resolute.20260812.022149
ros-lyrical-launch-ros=0.29.9-1resolute.20260812.024129
ros-lyrical-launch-testing=3.9.8-1resolute.20260728.175423
ros-lyrical-launch-testing-ament-cmake=3.9.8-1resolute.20260728.205136
ros-lyrical-launch-testing-ros=0.29.9-1resolute.20260812.024517
ros-lyrical-launch-xml=3.9.8-1resolute.20260728.175211
ros-lyrical-launch-yaml=3.9.8-1resolute.20260728.172929
ros-lyrical-libstatistics-collector=2.1.2-1resolute.20260812.012738
ros-lyrical-libyaml-vendor=1.8.1-3resolute.20260728.205613
ros-lyrical-lifecycle=0.37.9-1resolute.20260812.015506
ros-lyrical-lifecycle-msgs=2.4.5-1resolute.20260811.234650
ros-lyrical-logging-demo=0.37.9-1resolute.20260812.015543
ros-lyrical-lz4-cmake-module=0.33.3-1resolute.20260728.205656
ros-lyrical-magnetometer-broadcaster=6.9.0-1resolute.20260813.021541
ros-lyrical-map-msgs=2.6.1-1resolute.20260811.234335
ros-lyrical-marine-acoustic-msgs=2.1.0-3resolute.20260811.233749
ros-lyrical-mcap-vendor=0.33.3-1resolute.20260728.210724
ros-lyrical-mecanum-drive-controller=6.9.0-1resolute.20260813.021811
ros-lyrical-message-filters=7.4.2-1resolute.20260812.014855
ros-lyrical-motion-primitives-controllers=6.9.0-1resolute.20260813.020935
ros-lyrical-moveit=2.15.0-1resolute.20260814.213024
ros-lyrical-moveit-common=2.15.0-1resolute.20260813.020940
ros-lyrical-moveit-configs-utils=2.15.0-1resolute.20260813.021545
ros-lyrical-moveit-core=2.15.0-1resolute.20260814.181429
ros-lyrical-moveit-kinematics=2.15.0-1resolute.20260814.194910
ros-lyrical-moveit-msgs=2.7.2-1resolute.20260814.175542
ros-lyrical-moveit-planners=2.15.0-1resolute.20260814.201908
ros-lyrical-moveit-planners-chomp=2.15.0-1resolute.20260814.184504
ros-lyrical-moveit-planners-ompl=2.15.0-1resolute.20260814.195244
ros-lyrical-moveit-planners-stomp=2.15.0-1resolute.20260814.183549
ros-lyrical-moveit-plugins=2.15.0-1resolute.20260814.184435
ros-lyrical-moveit-ros=2.15.0-1resolute.20260814.204723
ros-lyrical-moveit-ros-benchmarks=2.15.0-1resolute.20260814.201408
ros-lyrical-moveit-ros-move-group=2.15.0-1resolute.20260814.195128
ros-lyrical-moveit-ros-occupancy-map-monitor=2.15.0-1resolute.20260814.185343
ros-lyrical-moveit-ros-planning=2.15.0-1resolute.20260814.192648
ros-lyrical-moveit-ros-planning-interface=2.15.0-1resolute.20260814.201720
ros-lyrical-moveit-ros-robot-interaction=2.15.0-1resolute.20260814.194810
ros-lyrical-moveit-ros-visualization=2.15.0-1resolute.20260814.202013
ros-lyrical-moveit-ros-warehouse=2.15.0-1resolute.20260814.195656
ros-lyrical-moveit-setup-app-plugins=2.15.0-1resolute.20260814.210341
ros-lyrical-moveit-setup-assistant=2.15.0-1resolute.20260814.212621
ros-lyrical-moveit-setup-controllers=2.15.0-1resolute.20260814.210341
ros-lyrical-moveit-setup-core-plugins=2.15.0-1resolute.20260814.210607
ros-lyrical-moveit-setup-framework=2.15.0-1resolute.20260814.210017
ros-lyrical-moveit-setup-srdf-plugins=2.15.0-1resolute.20260814.210346
ros-lyrical-moveit-simple-controller-manager=2.15.0-1resolute.20260814.183549
ros-lyrical-nav-msgs=5.9.3-1resolute.20260811.232935
ros-lyrical-object-recognition-msgs=2.0.0-6resolute.20260811.234429
ros-lyrical-octomap-msgs=2.0.1-3resolute.20260811.233803
ros-lyrical-omni-wheel-drive-controller=6.9.0-1resolute.20260813.021006
ros-lyrical-ompl=2.0.1-3resolute.20260728.173004
ros-lyrical-orocos-kdl-vendor=0.8.0-3resolute.20260728.205531
ros-lyrical-osqp-vendor=1.0.0-1resolute.20260811.125853
ros-lyrical-pal-statistics=2.8.0-1resolute.20260812.020510
ros-lyrical-pal-statistics-msgs=2.8.0-1resolute.20260811.215029
ros-lyrical-parallel-gripper-controller=6.9.0-1resolute.20260813.021750
ros-lyrical-pcl-conversions=2.10.0-1resolute.20260812.065431
ros-lyrical-pcl-msgs=1.0.0-10resolute.20260812.064641
ros-lyrical-pcl-ros=2.10.0-1resolute.20260812.070823
ros-lyrical-pendulum-control=0.37.9-1resolute.20260812.015613
ros-lyrical-pendulum-msgs=0.37.9-1resolute.20260811.234822
ros-lyrical-pid-controller=6.9.0-1resolute.20260813.021755
ros-lyrical-pilz-industrial-motion-planner=2.15.0-1resolute.20260814.200329
ros-lyrical-pluginlib=5.8.4-3resolute.20260728.212925
ros-lyrical-point-cloud-transport=5.4.3-1resolute.20260812.021543
ros-lyrical-pose-broadcaster=6.9.0-1resolute.20260813.021008
ros-lyrical-python-qt-binding=2.5.5-1resolute.20260728.205956
ros-lyrical-qt-dotgraph=2.11.1-1resolute.20260728.210436
ros-lyrical-qt-gui=2.11.1-1resolute.20260728.210439
ros-lyrical-qt-gui-cpp=2.11.1-1resolute.20260728.213227
ros-lyrical-qt-gui-py-common=2.11.1-1resolute.20260728.210443
ros-lyrical-quality-of-service-demo-cpp=0.37.9-1resolute.20260812.024540
ros-lyrical-quality-of-service-demo-py=0.37.9-1resolute.20260812.021217
ros-lyrical-random-numbers=2.0.5-1resolute.20260728.210002
ros-lyrical-range-sensor-broadcaster=6.9.0-1resolute.20260813.021034
ros-lyrical-rcl=10.4.4-1resolute.20260812.012321
ros-lyrical-rcl-action=10.4.4-1resolute.20260812.012801
ros-lyrical-rclcpp=32.0.2-1resolute.20260812.014037
ros-lyrical-rclcpp-action=32.0.2-1resolute.20260812.014919
ros-lyrical-rclcpp-components=32.0.2-1resolute.20260812.015019
ros-lyrical-rclcpp-lifecycle=32.0.2-1resolute.20260812.014952
ros-lyrical-rcl-interfaces=2.4.5-1resolute.20260811.234851
ros-lyrical-rcl-lifecycle=10.4.4-1resolute.20260812.012718
ros-lyrical-rcl-logging-implementation=3.4.1-3resolute.20260812.011632
ros-lyrical-rcl-logging-interface=3.4.1-3resolute.20260812.010932
ros-lyrical-rcl-logging-spdlog=3.4.1-3resolute.20260812.011255
ros-lyrical-rclpy=10.0.10-1resolute.20260812.014024
ros-lyrical-rcl-yaml-param-parser=10.4.4-1resolute.20260812.010939
ros-lyrical-rcpputils=2.14.5-1resolute.20260728.210316
ros-lyrical-rcutils=7.1.2-1resolute.20260728.210016
ros-lyrical-realtime-tools=5.2.0-3resolute.20260812.023617
ros-lyrical-resource-retriever=3.9.3-3resolute.20260812.010941
ros-lyrical-resource-retriever-interfaces=0.0.3-1resolute.20260811.215055
ros-lyrical-resource-retriever-service-plugin=0.0.3-1resolute.20260812.015310
ros-lyrical-rmw=7.10.1-5resolute.20260728.210946
ros-lyrical-rmw-dds-common=6.0.0-3resolute.20260811.214453
ros-lyrical-rmw-fastrtps-cpp=9.4.9-1resolute.20260812.000633
ros-lyrical-rmw-fastrtps-shared-cpp=9.4.9-1resolute.20260811.235827
ros-lyrical-rmw-implementation=3.1.6-1resolute.20260812.001853
ros-lyrical-rmw-implementation-cmake=7.10.1-5resolute.20260728.210014
ros-lyrical-rmw-security-common=7.10.1-5resolute.20260728.211356
ros-lyrical-rmw-test-fixture=0.15.8-1resolute.20260728.211417
ros-lyrical-rmw-test-fixture-implementation=0.15.8-1resolute.20260812.002527
ros-lyrical-robot-state-publisher=3.5.5-3resolute.20260812.020221
ros-lyrical-ros2action=0.40.8-1resolute.20260812.022257
ros-lyrical-ros2bag=0.33.3-1resolute.20260812.034142
ros-lyrical-ros2cli=0.40.8-1resolute.20260812.022130
ros-lyrical-ros2cli-common-extensions=0.5.2-3resolute.20260812.025525
ros-lyrical-ros2component=0.40.8-1resolute.20260812.025106
ros-lyrical-ros2-control=6.9.0-1resolute.20260812.034329
ros-lyrical-ros2controlcli=6.9.0-1resolute.20260812.032651
ros-lyrical-ros2-control-cmake=0.3.0-3resolute.20260728.210022
ros-lyrical-ros2-controllers=6.9.0-1resolute.20260813.022832
ros-lyrical-ros2-control-test-assets=6.9.0-1resolute.20260810.231204
ros-lyrical-ros2doctor=0.40.8-1resolute.20260812.022413
ros-lyrical-ros2interface=0.40.8-1resolute.20260812.024852
ros-lyrical-ros2launch=0.29.9-1resolute.20260812.025115
ros-lyrical-ros2lifecycle=0.40.8-1resolute.20260812.023056
ros-lyrical-ros2multicast=0.40.8-1resolute.20260812.024851
ros-lyrical-ros2node=0.40.8-1resolute.20260812.022937
ros-lyrical-ros2param=0.40.8-1resolute.20260812.023104
ros-lyrical-ros2pkg=0.40.8-1resolute.20260812.024906
ros-lyrical-ros2plugin=5.8.4-3resolute.20260812.025108
ros-lyrical-ros2run=0.40.8-1resolute.20260812.025152
ros-lyrical-ros2service=0.40.8-1resolute.20260812.022915
ros-lyrical-ros2topic=0.40.8-1resolute.20260812.022955
ros-lyrical-rosbag2=0.33.3-1resolute.20260812.034437
ros-lyrical-rosbag2-compression=0.33.3-1resolute.20260812.031247
ros-lyrical-rosbag2-compression-zstd=0.33.3-1resolute.20260812.033924
ros-lyrical-rosbag2-cpp=0.33.3-1resolute.20260812.024604
ros-lyrical-rosbag2-interfaces=0.33.3-1resolute.20260811.213023
ros-lyrical-rosbag2-py=0.33.3-1resolute.20260812.033351
ros-lyrical-rosbag2-storage=0.33.3-1resolute.20260812.023725
ros-lyrical-rosbag2-storage-default-plugins=0.33.3-1resolute.20260812.033812
ros-lyrical-rosbag2-storage-mcap=0.33.3-1resolute.20260812.031353
ros-lyrical-rosbag2-storage-sqlite3=0.33.3-1resolute.20260812.031643
ros-lyrical-rosbag2-transport=0.33.3-1resolute.20260812.031909
ros-lyrical-ros-base=0.13.0-3resolute.20260812.070046
ros-lyrical-ros-core=0.13.0-3resolute.20260812.025814
ros-lyrical-ros-environment=4.5.1-1resolute.20260728.172811
ros-lyrical-rosgraph-msgs=2.4.5-1resolute.20260811.235432
ros-lyrical-ros-gz-bridge=3.0.9-1resolute.20260817.170928
ros-lyrical-ros-gz-interfaces=3.0.9-1resolute.20260811.235421
ros-lyrical-ros-gz-sim=3.0.9-1resolute.20260812.025049
ros-lyrical-rosidl-adapter=5.2.1-1resolute.20260728.204010
ros-lyrical-rosidl-buffer=5.2.1-1resolute.20260728.210115
ros-lyrical-rosidl-buffer-backend=5.2.1-1resolute.20260728.211422
ros-lyrical-rosidl-buffer-backend-registry=5.2.1-1resolute.20260728.213234
ros-lyrical-rosidl-buffer-py=5.2.1-1resolute.20260728.210209
ros-lyrical-rosidl-cli=5.2.1-1resolute.20260728.173046
ros-lyrical-rosidl-cmake=5.2.1-1resolute.20260728.210427
ros-lyrical-rosidl-core-generators=0.4.3-3resolute.20260811.194301
ros-lyrical-rosidl-core-runtime=0.4.3-3resolute.20260728.212309
ros-lyrical-rosidl-default-generators=1.8.1-3resolute.20260811.211639
ros-lyrical-rosidl-default-runtime=1.8.1-3resolute.20260811.210711
ros-lyrical-rosidl-dynamic-typesupport=0.4.1-3resolute.20260728.210642
ros-lyrical-rosidl-dynamic-typesupport-fastrtps=0.5.1-3resolute.20260728.210954
ros-lyrical-rosidl-generator-c=5.2.1-1resolute.20260728.210700
ros-lyrical-rosidl-generator-cpp=5.2.1-1resolute.20260728.210943
ros-lyrical-rosidl-generator-py=0.27.2-3resolute.20260728.211553
ros-lyrical-rosidl-generator-rs=0.5.0-2resolute.20260811.194003
ros-lyrical-rosidl-generator-type-description=5.2.1-1resolute.20260728.210206
ros-lyrical-rosidl-parser=5.2.1-1resolute.20260728.210114
ros-lyrical-rosidl-pycommon=5.2.1-1resolute.20260728.210228
ros-lyrical-rosidl-runtime-c=5.2.1-1resolute.20260728.210328
ros-lyrical-rosidl-runtime-cpp=5.2.1-1resolute.20260728.210648
ros-lyrical-rosidl-runtime-py=0.15.2-3resolute.20260728.210536
ros-lyrical-rosidl-typesupport-c=3.4.2-3resolute.20260728.211303
ros-lyrical-rosidl-typesupport-cpp=3.4.2-3resolute.20260728.211628
ros-lyrical-rosidl-typesupport-fastrtps-c=3.9.5-3resolute.20260728.211956
ros-lyrical-rosidl-typesupport-fastrtps-cpp=3.9.5-3resolute.20260728.211709
ros-lyrical-rosidl-typesupport-interface=5.2.1-1resolute.20260728.210128
ros-lyrical-rosidl-typesupport-introspection-c=5.2.1-1resolute.20260728.210952
ros-lyrical-rosidl-typesupport-introspection-cpp=5.2.1-1resolute.20260728.211325
ros-lyrical-ros-workspace=1.0.3-9resolute.20260728.162902
ros-lyrical-rpyutils=0.7.2-3resolute.20260728.174949
ros-lyrical-rqt-action=2.5.0-1resolute.20260812.025524
ros-lyrical-rqt-bag=2.2.5-1resolute.20260812.034206
ros-lyrical-rqt-bag-plugins=2.2.5-1resolute.20260812.034656
ros-lyrical-rqt-common-plugins=1.2.0-5resolute.20260812.034821
ros-lyrical-rqt-console=2.4.4-1resolute.20260812.023325
ros-lyrical-rqt-graph=1.8.5-1resolute.20260812.023457
ros-lyrical-rqt-gui=1.10.6-1resolute.20260812.022147
ros-lyrical-rqt-gui-cpp=1.10.6-1resolute.20260812.023746
ros-lyrical-rqt-gui-py=1.10.6-1resolute.20260812.023155
ros-lyrical-rqt-image-view=2.0.5-3resolute.20260812.024710
ros-lyrical-rqt-msg=1.7.4-1resolute.20260812.023530
ros-lyrical-rqt-plot=1.7.6-1resolute.20260812.023316
ros-lyrical-rqt-publisher=1.10.4-1resolute.20260812.023431
ros-lyrical-rqt-py-common=1.10.6-1resolute.20260812.022236
ros-lyrical-rqt-py-console=1.5.3-1resolute.20260812.023448
ros-lyrical-rqt-reconfigure=1.8.6-1resolute.20260812.023511
ros-lyrical-rqt-service-caller=1.5.4-1resolute.20260812.025639
ros-lyrical-rqt-shell=1.4.2-1resolute.20260812.025614
ros-lyrical-rqt-srv=1.4.1-3resolute.20260812.025549
ros-lyrical-rqt-topic=2.1.2-1resolute.20260812.023437
ros-lyrical-rsl=1.3.0-3resolute.20260812.023757
ros-lyrical-rttest=0.20.1-1resolute.20260728.210200
ros-lyrical-ruckig=0.9.2-6resolute.20260728.172957
ros-lyrical-rviz2=15.2.5-1resolute.20260812.080038
ros-lyrical-rviz-common=15.2.5-1resolute.20260812.020303
ros-lyrical-rviz-default-plugins=15.2.5-1resolute.20260812.065920
ros-lyrical-rviz-ogre-vendor=15.2.5-1resolute.20260728.210151
ros-lyrical-rviz-rendering=15.2.5-1resolute.20260812.011315
ros-lyrical-sdformat-urdf=2.1.1-1resolute.20260812.012055
ros-lyrical-sdformat-vendor=0.3.4-1resolute.20260728.211924
ros-lyrical-sdl2-vendor=3.3.0-4resolute.20260728.210149
ros-lyrical-sensor-msgs=5.9.3-1resolute.20260811.233053
ros-lyrical-sensor-msgs-py=5.9.3-1resolute.20260812.064948
ros-lyrical-service-msgs=2.4.5-1resolute.20260811.200407
ros-lyrical-shape-msgs=5.9.3-1resolute.20260811.233816
ros-lyrical-simulation-interfaces=2.1.0-3resolute.20260811.233050
ros-lyrical-spdlog-vendor=1.8.0-3resolute.20260728.210243
ros-lyrical-srdfdom=2.0.9-3resolute.20260812.022759
ros-lyrical-sros2=0.16.6-1resolute.20260812.023125
ros-lyrical-sros2-cmake=0.16.6-1resolute.20260812.024945
ros-lyrical-state-interfaces-broadcaster=6.9.0-1resolute.20260813.021331
ros-lyrical-statistics-msgs=2.4.5-1resolute.20260811.213037
ros-lyrical-std-msgs=5.9.3-1resolute.20260811.213219
ros-lyrical-std-srvs=5.9.3-1resolute.20260811.234022
ros-lyrical-steering-controllers-library=6.9.0-1resolute.20260813.021509
ros-lyrical-stereo-msgs=5.9.3-1resolute.20260811.234335
ros-lyrical-stomp=0.1.2-5resolute.20260728.173012
ros-lyrical-tango-icons-vendor=0.5.1-3resolute.20260728.210308
ros-lyrical-tcb-span=2.0.3-1resolute.20260728.210330
ros-lyrical-teleop-twist-joy=2.6.5-3resolute.20260812.022254
ros-lyrical-teleop-twist-keyboard=2.4.1-3resolute.20260812.024553
ros-lyrical-tf2=0.45.9-1resolute.20260812.011045
ros-lyrical-tf2-bullet=0.45.9-1resolute.20260812.020722
ros-lyrical-tf2-eigen=0.45.9-1resolute.20260812.020513
ros-lyrical-tf2-eigen-kdl=0.45.9-1resolute.20260812.011952
ros-lyrical-tf2-geometry-msgs=0.45.9-1resolute.20260812.025229
ros-lyrical-tf2-kdl=0.45.9-1resolute.20260812.025208
ros-lyrical-tf2-msgs=0.45.9-1resolute.20260811.233056
ros-lyrical-tf2-py=0.45.9-1resolute.20260812.024611
ros-lyrical-tf2-ros=0.45.9-1resolute.20260812.015530
ros-lyrical-tf2-ros-py=0.45.9-1resolute.20260812.025028
ros-lyrical-tf2-sensor-msgs=0.45.9-1resolute.20260812.065458
ros-lyrical-tf2-tools=0.45.9-1resolute.20260812.025315
ros-lyrical-tlsf=0.11.1-3resolute.20260728.210355
ros-lyrical-tlsf-cpp=0.20.1-1resolute.20260812.015124
ros-lyrical-topic-monitor=0.37.9-1resolute.20260812.024354
ros-lyrical-tracetools=8.10.2-1resolute.20260728.204752
ros-lyrical-trajectory-msgs=5.9.3-1resolute.20260811.233349
ros-lyrical-transmission-interface=6.9.0-1resolute.20260812.033825
ros-lyrical-tricycle-controller=6.9.0-1resolute.20260813.021410
ros-lyrical-tricycle-steering-controller=6.9.0-1resolute.20260813.022151
ros-lyrical-turtlesim=1.10.9-1resolute.20260812.015436
ros-lyrical-turtlesim-msgs=1.10.9-1resolute.20260811.213233
ros-lyrical-type-description-interfaces=2.4.5-1resolute.20260811.210326
ros-lyrical-uncrustify-vendor=3.2.0-3resolute.20260728.210418
ros-lyrical-unique-identifier-msgs=2.8.1-3resolute.20260811.194456
ros-lyrical-urdf=2.13.2-3resolute.20260812.011426
ros-lyrical-urdfdom=6.0.0-3resolute.20260728.205537
ros-lyrical-urdfdom-headers=3.0.0-3resolute.20260728.173048
ros-lyrical-urdfdom-py=1.2.1-4resolute.20260812.022205
ros-lyrical-urdf-parser-plugin=2.13.2-3resolute.20260812.011111
ros-lyrical-vision-msgs=4.2.0-3resolute.20260811.233840
ros-lyrical-visualization-msgs=5.9.3-1resolute.20260811.234235
ros-lyrical-warehouse-ros=2.0.8-1resolute.20260813.021508
ros-lyrical-xacro=2.1.1-3resolute.20260728.204820
ros-lyrical-yaml-cpp-vendor=9.2.1-3resolute.20260728.210605
ros-lyrical-zenoh-cpp-vendor=0.10.5-1resolute.20260728.210611
ros-lyrical-zstd-cmake-module=0.33.3-1resolute.20260728.210616

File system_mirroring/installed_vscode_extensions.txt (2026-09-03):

ms-iot.vscode-ros
ms-python.debugpy
ms-python.python
ms-python.vscode-pylance
ms-python.vscode-python-envs
ms-vscode.cmake-tools
ms-vscode.cpp-devtools
ms-vscode.cpptools
ms-vscode.cpptools-extension-pack
ms-vscode.cpptools-themes
platformio.platformio-ide
redhat.vscode-xml
redhat.vscode-yaml

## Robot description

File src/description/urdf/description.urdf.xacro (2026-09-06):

<?xml version="1.0"?>
<robot xmlns:xacro="http://www.ros.org/wiki/xacro" name="dast_1">

    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
    <xacro:arg name="is_sim" default="true"/>
    <xacro:property name="path" value="package://description/meshes" />
    <xacro:property name="scale" value="0.01 0.01 0.01" />
    <xacro:property name="PI" value="3.14159265359" />
    <xacro:property name="effort" value="20.0" />
    <xacro:property name="velocity" value="10.0" />

    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
    <xacro:property name="kinect_xyz" value="-9.0 3.1 3.9" />
    <xacro:property name="kinect_rpy" value="0 0.279 0" />

    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
    <xacro:property name="kinect_hfov" value="1.0542" />
    <xacro:property name="kinect_clip_near" value="5.0" />
    <xacro:property name="kinect_clip_far" value="40.0" />

    <xacro:macro name="default_inertial" params="mass">
        <inertial>
            <origin xyz="0 0 0" rpy="0 0 0"/>
            <mass value="${mass}" />
            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
        </inertial>
    </xacro:macro>

    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
    <link name="world"/>

    <link name="base_link">
        <xacro:default_inertial mass="0.2"/>
        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
    </link>

    <link name="rotary_link">
        <xacro:default_inertial mass="0.05"/>
        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
    </link>

    <link name="arm_1_link">
        <xacro:default_inertial mass="0.1"/>
        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
    </link>

    <link name="arm_2_link">
        <xacro:default_inertial mass="0.1"/>
        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
    </link>

    <link name="arm_3_link">
        <xacro:default_inertial mass="0.1"/>
        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
    </link>

    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
    <link name="wrist_link">
        <xacro:default_inertial mass="0.01"/>
    </link>

    <link name="gripper_link">
        <xacro:default_inertial mass="0.05"/>
        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
    </link>

    <link name="tip"/>

    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
    <joint name="virtual_joint" type="fixed">
        <parent link="world"/>
        <child link="base_link"/>
        <origin xyz="0 0 0" rpy="0 0 0"/>
    </joint> 

    <joint name ="joint_1" type="revolute">
        <parent link="base_link"/>
        <child link = "rotary_link"/>
        <origin xyz="0 0 1.47"/>
        <axis xyz="0 0 1"/>
        <limit lower="-${PI / 2}" upper="${PI / 2}" effort="${effort}" velocity="${velocity}"/>
    </joint>

    <joint name ="joint_2" type="revolute">
        <parent link="rotary_link"/>
        <child link = "arm_1_link"/>
        <origin xyz="0 0 0"/>
        <axis xyz="1 0 0"/>
        <limit lower="-${PI / 2}" upper="${PI / 2}" effort="${effort}" velocity="${velocity}"/>
    </joint>

    <joint name ="joint_3" type="revolute">
        <parent link="arm_1_link"/>
        <child link = "arm_2_link"/>
        <origin xyz="0 0 1.545"/>
        <axis xyz="1 0 0"/>
        <limit lower="-${PI / 2}" upper="${PI / 2}" effort="${effort}" velocity="${velocity}"/>
    </joint>

    <joint name ="joint_4" type="revolute">
        <parent link="arm_2_link"/>
        <child link = "arm_3_link"/>
        <origin xyz="0 0 1.945"/>
        <axis xyz="1 0 0"/>
        <limit lower="-${PI / 2}" upper="${PI / 2}" effort="${effort}" velocity="${velocity}"/>
    </joint>

    <joint name ="joint_5" type="revolute">
        <parent link="arm_3_link"/>
        <child link = "wrist_link"/>
        <origin xyz="0 0 0.88"/>
        <axis xyz="0 0 1"/>
        <limit lower="-${PI / 2}" upper="${PI / 2}" effort="${effort}" velocity="${velocity}"/>
    </joint>

    <joint name ="joint_6" type="revolute">
        <parent link="wrist_link"/>
        <child link = "gripper_link"/>
        <origin xyz="0 0 0"/>
        <axis xyz="0 1 0"/>
        <limit lower="-${PI / 2}" upper="${PI / 2}" effort="${effort}" velocity="${velocity}"/>
    </joint>

    <joint name="virtual_joint_tip" type="fixed">
        <parent link="gripper_link"/>
        <child link="tip"/>
        <origin xyz="0 0 1.75" rpy="0 0 0"/>
    </joint> 

    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
    <link name="kinect_link">
        <xacro:default_inertial mass="0.5"/>
        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
    </link>

    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
    <link name="kinect_rgb_optical_frame"/>

    <joint name="kinect_joint" type="fixed">
        <parent link="base_link"/>
        <child link="kinect_link"/>
        <origin xyz="${kinect_xyz}" rpy="${kinect_rpy}"/>
    </joint>

    <joint name="kinect_optical_joint" type="fixed">
        <parent link="kinect_link"/>
        <child link="kinect_rgb_optical_frame"/>
        <origin xyz="0 0 0" rpy="-${PI/2} 0 -${PI/2}"/>
    </joint>

    <xacro:if value="$(arg is_sim)">
        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
    </xacro:if>

    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
    <xacro:include filename="$(find description)/urdf/control.xacro" />

</robot>

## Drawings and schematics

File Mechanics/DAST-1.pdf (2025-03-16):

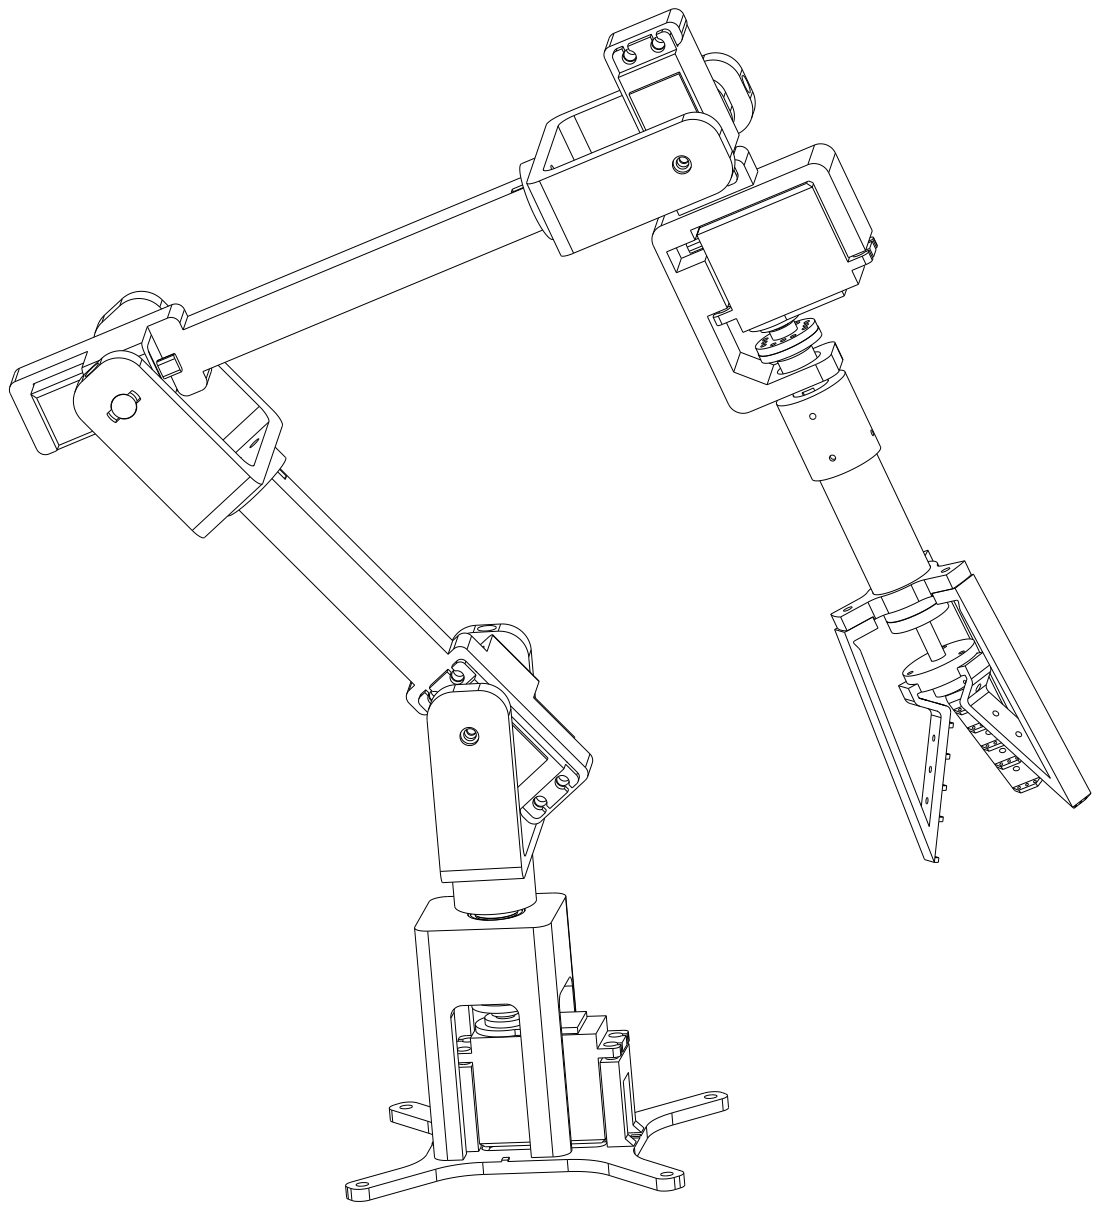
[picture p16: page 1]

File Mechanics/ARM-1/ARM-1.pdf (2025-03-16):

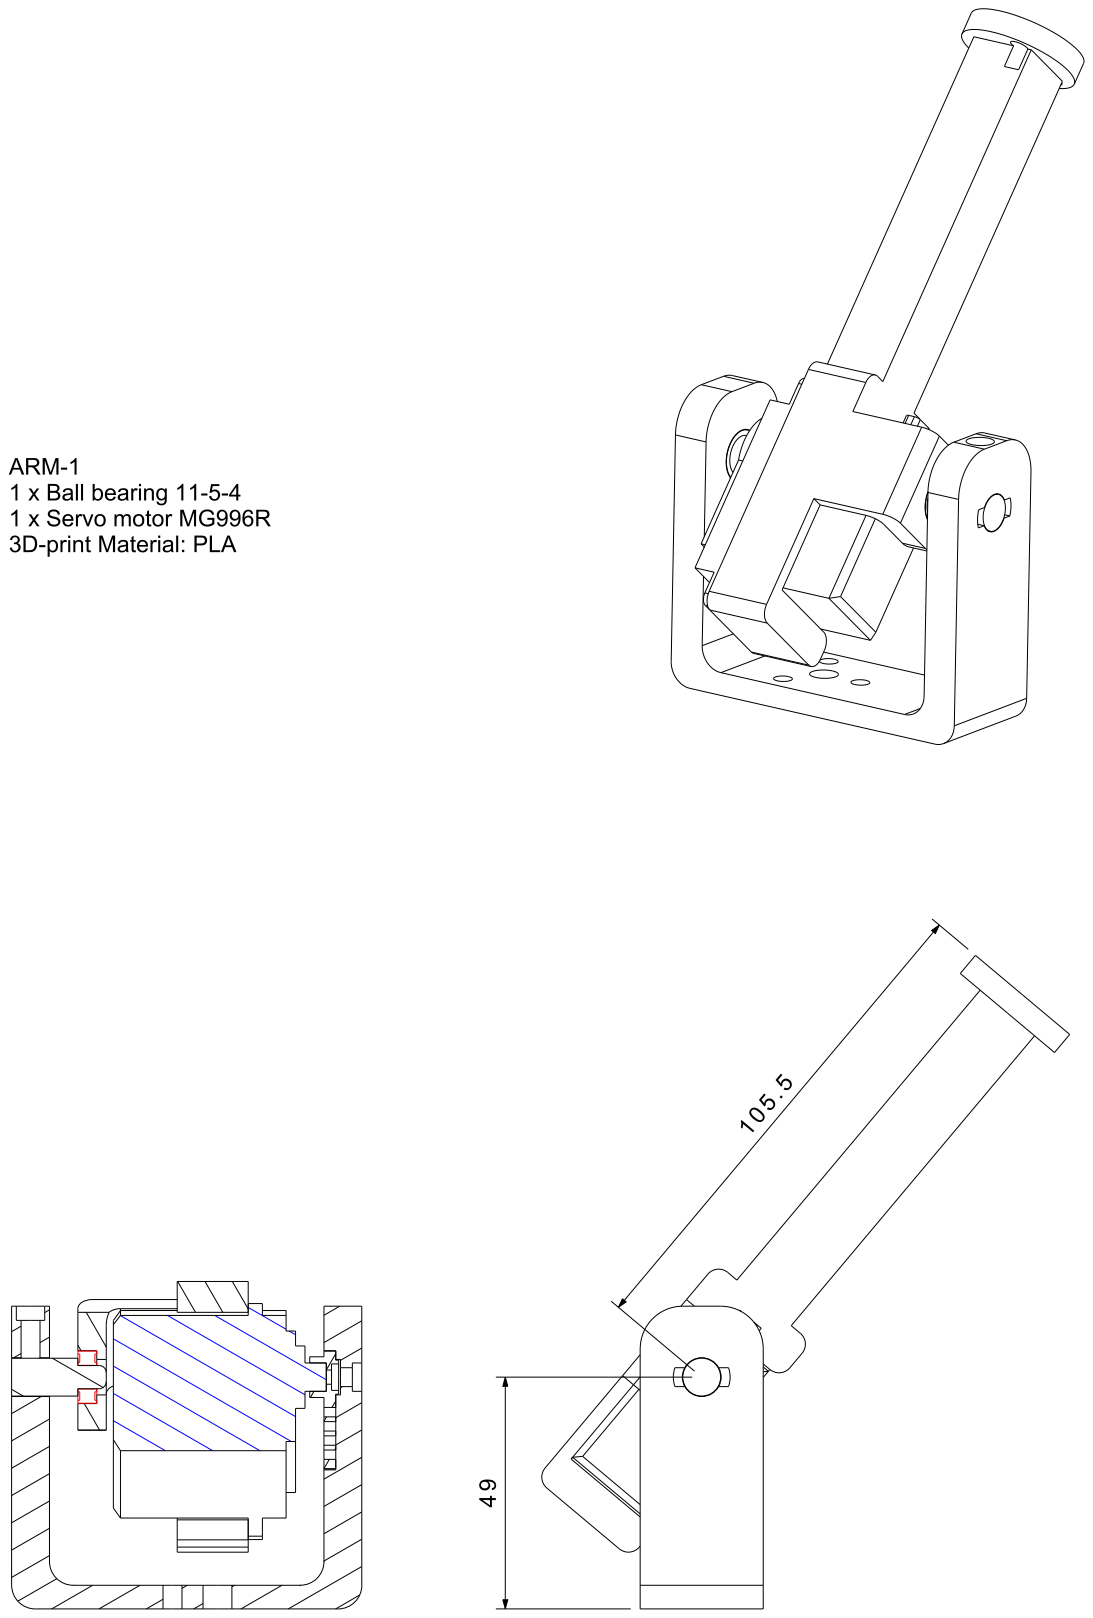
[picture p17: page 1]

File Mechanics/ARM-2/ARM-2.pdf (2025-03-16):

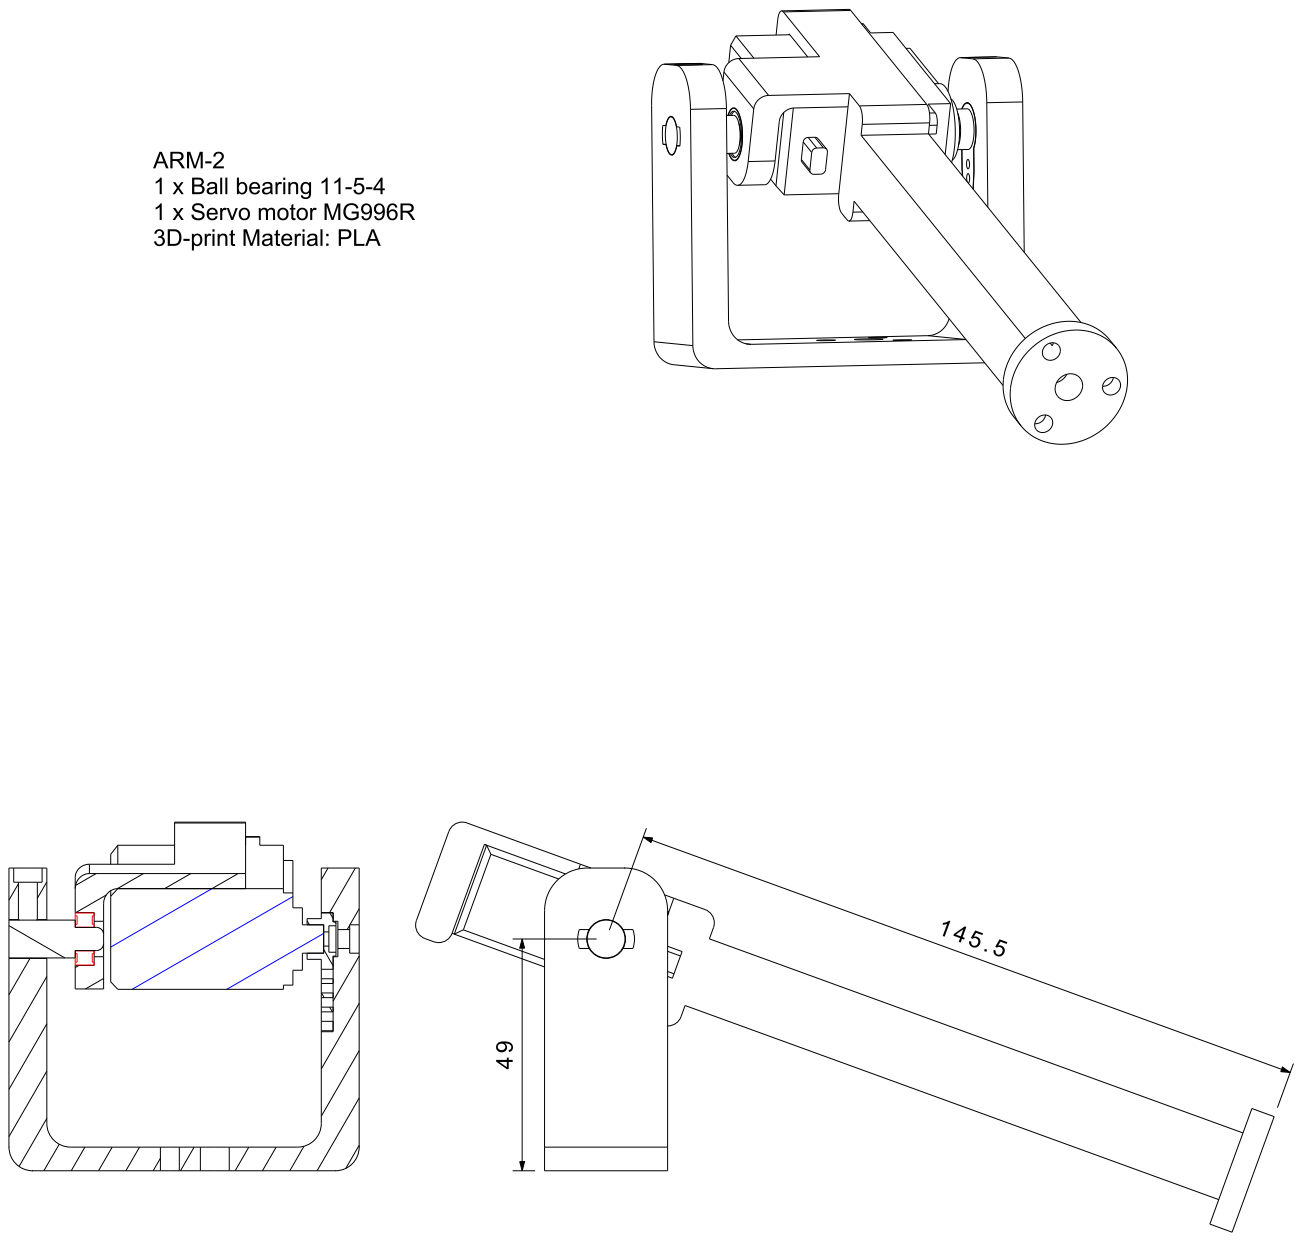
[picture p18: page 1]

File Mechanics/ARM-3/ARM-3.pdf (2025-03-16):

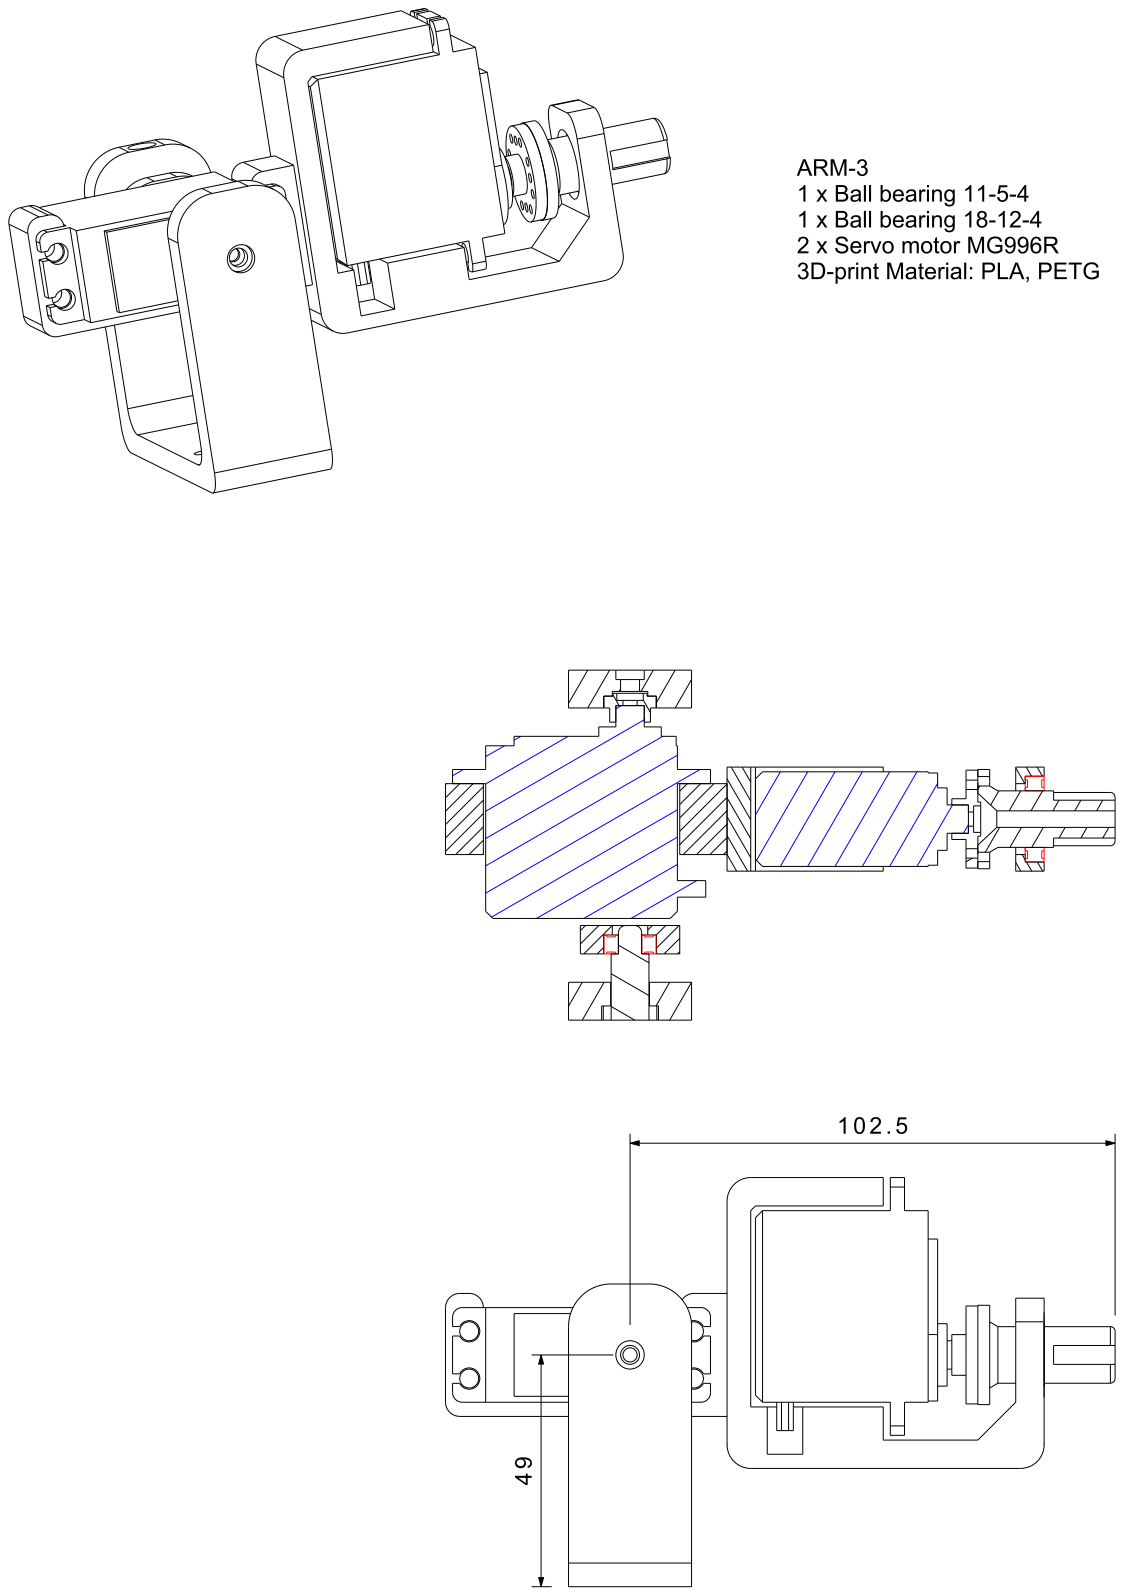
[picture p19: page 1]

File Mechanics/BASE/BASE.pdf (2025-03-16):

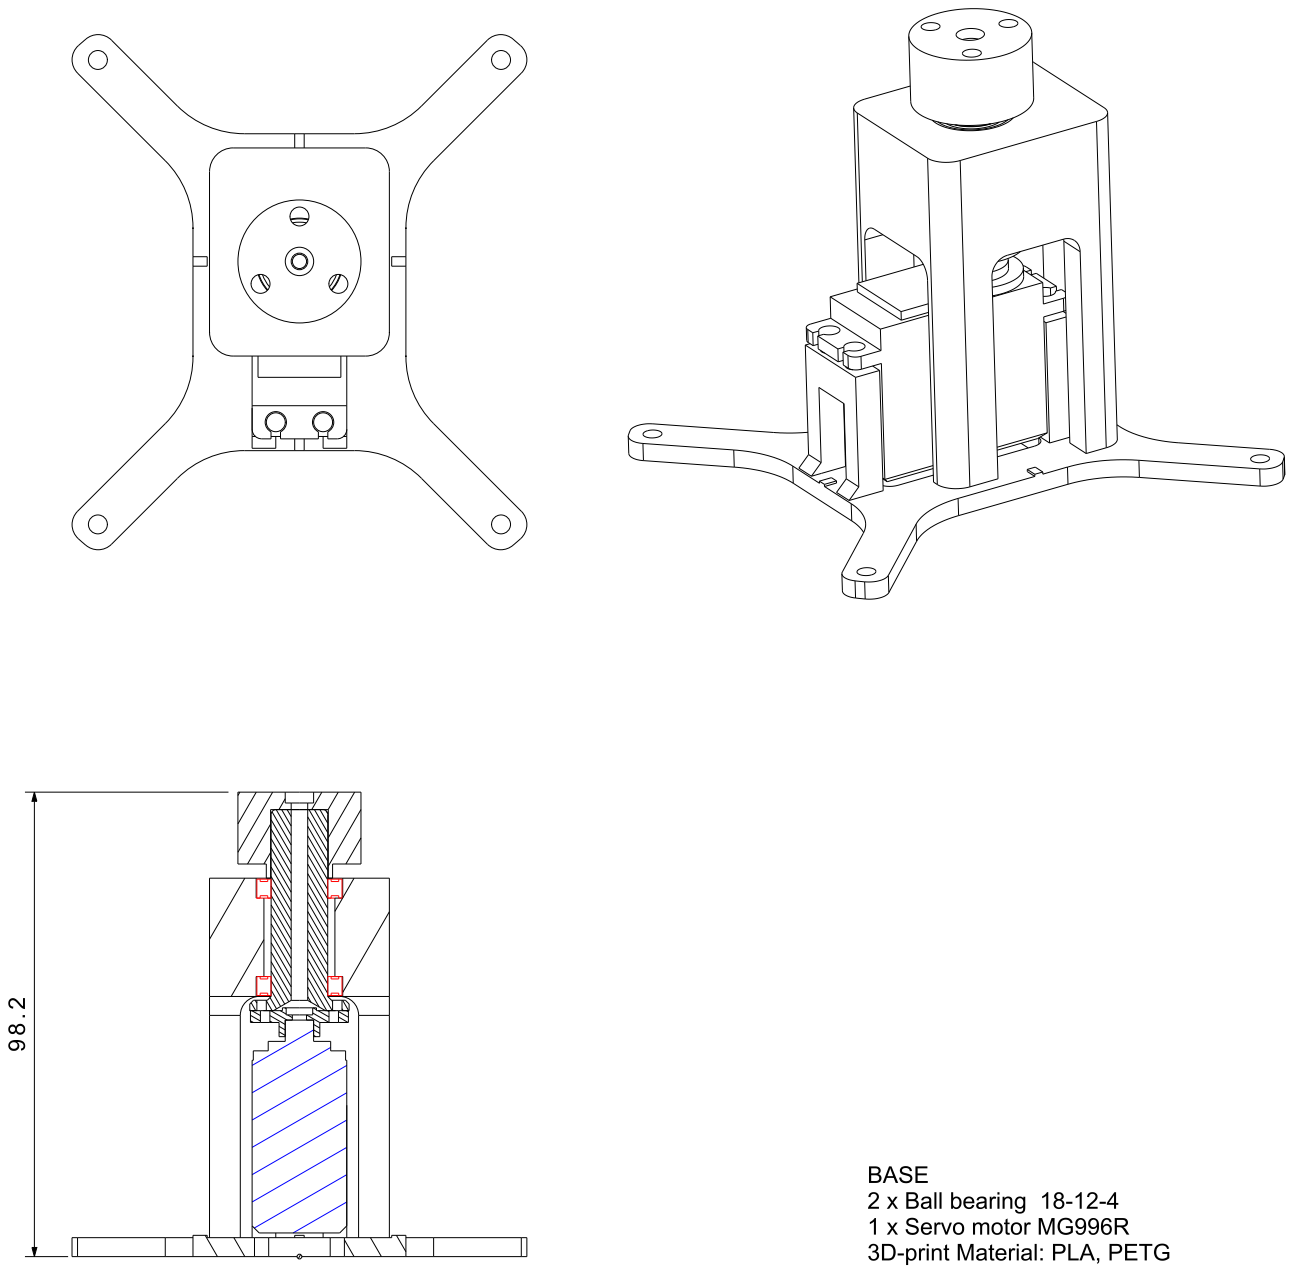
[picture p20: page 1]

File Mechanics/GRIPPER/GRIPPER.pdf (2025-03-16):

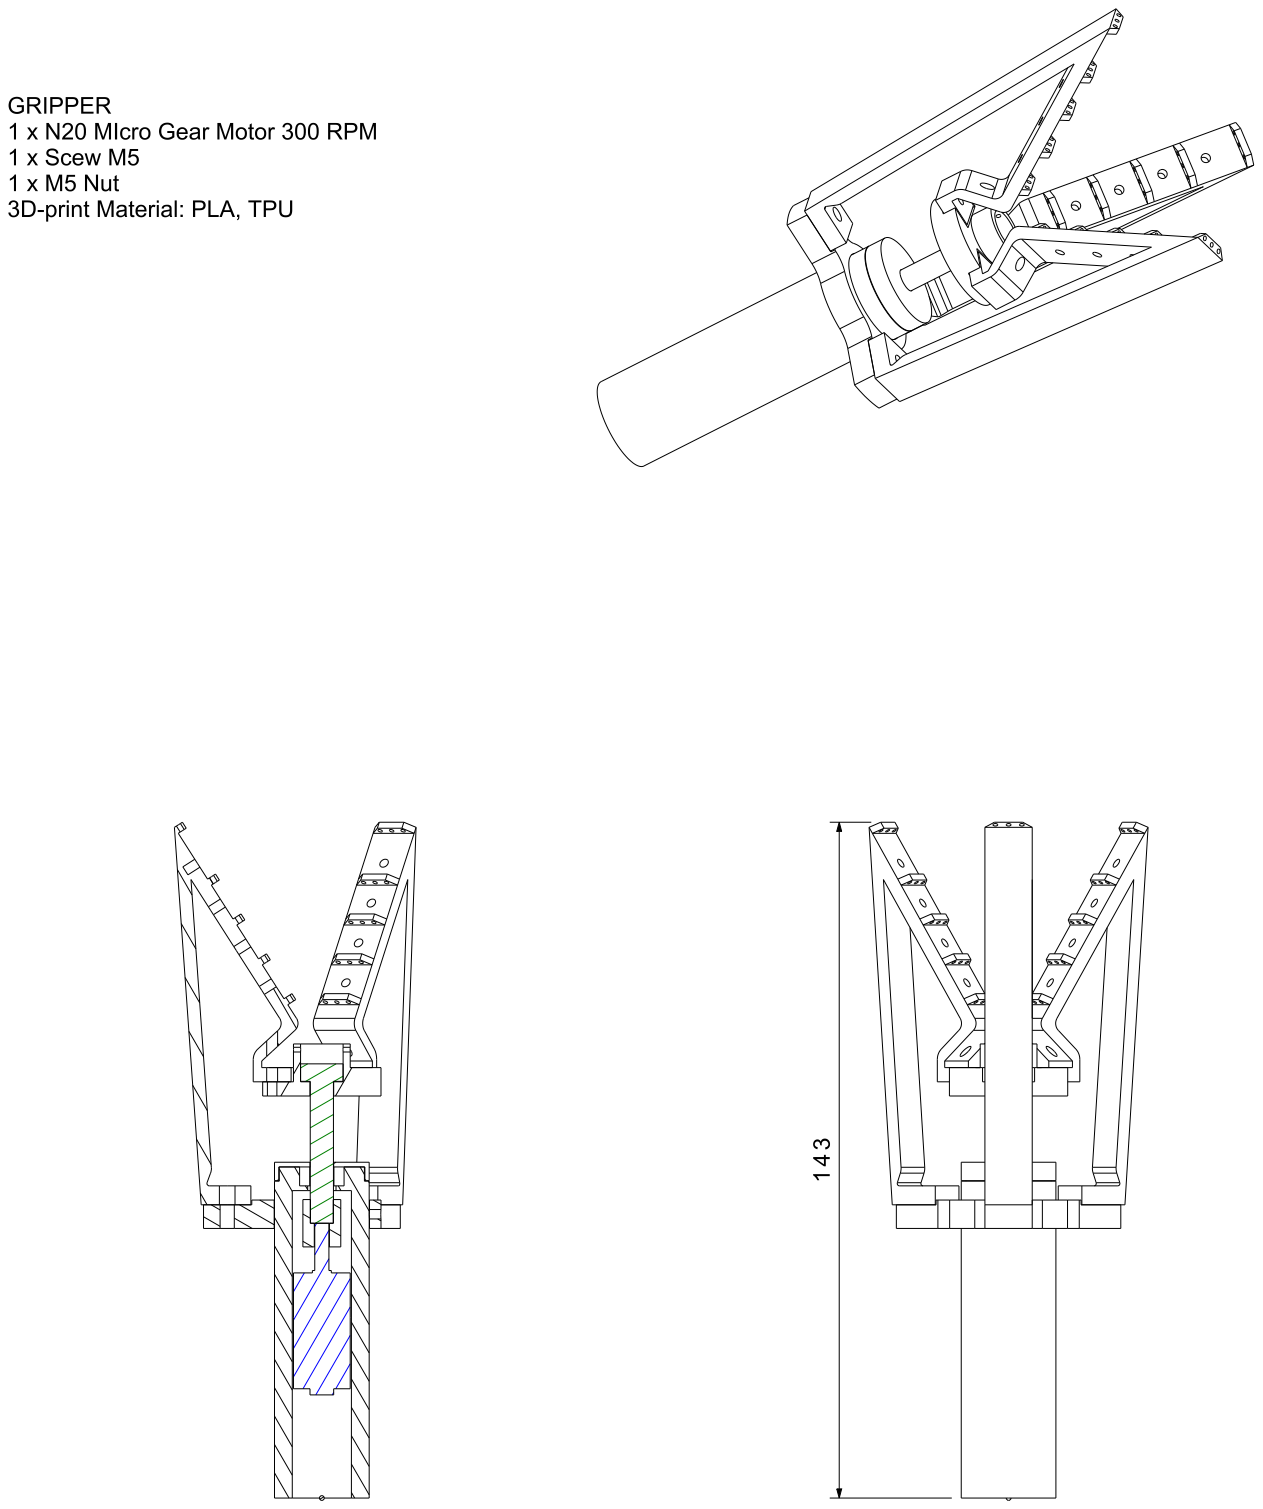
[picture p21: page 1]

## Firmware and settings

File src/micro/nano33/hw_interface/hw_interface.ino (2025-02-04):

#include <Servo.h>
#include <vector>

#define JOINT_1_PIN 8
#define JOINT_2_PIN 9
#define JOINT_3_PIN 10
#define JOINT_4_PIN 11
#define JOINT_5_PIN 12

#define JOINT_1_START 0
#define JOINT_2_START 0
#define JOINT_3_START 0
#define JOINT_4_START 0
#define JOINT_5_START 0

// Register the servo motors of each joint
Servo joint_1;
Servo joint_2; 
Servo joint_3; 
Servo joint_4; 
Servo joint_5; 

// Slow movement
// void reach_goal_1(Servo& motor, int goal){
//   if(goal>=motor.read()){
//     // goes from the start point degrees to the end point degrees
//     for (int pos = motor.read(); pos <= goal; pos += 1) { 
//       motor.write(pos);     
//       delay(1);                       
//     }
//   } else{
//     // goes from the end point degrees to the start point degrees
//     for (int pos = motor.read(); pos >= goal; pos -= 1) { 
//       motor.write(pos);     
//       delay(1);                       
//     }
//   }
// }

void reach_goal(Servo *motors, int *goals, int delay_){
  for (int clk=0; clk<180; clk++) { 
    for (int i=0; i<5; i++) {
      int read_ = motors[i].read();
      if(read_ < goals[i]){
        motors[i].write(read_++);
      }
    }
    delay(delay_);                       
  }
}

// Split String
std::vector<String> split_string(String data, char separator){
  std::vector<String> output;
  int startIndex = 0;
  int endIndex = 0;

  while ((endIndex = data.indexOf(separator, startIndex)) != -1) {
    output.push_back(data.substring(startIndex, endIndex));
    startIndex = endIndex + 1;
  }
  output.push_back(data.substring(startIndex));
  delay(1000);
  return output;
}

void setup() {
  joint_1.attach(JOINT_1_PIN);
  joint_2.attach(JOINT_2_PIN);
  joint_3.attach(JOINT_3_PIN);
  joint_4.attach(JOINT_4_PIN);
  joint_5.attach(JOINT_5_PIN);

  joint_1.write(JOINT_1_START);
  joint_2.write(JOINT_2_START);
  joint_3.write(JOINT_3_START);
  joint_4.write(JOINT_4_START);
  joint_5.write(JOINT_5_START);

  Serial.begin(115200);
  Serial.setTimeout(1);
}

void loop() {
  if (Serial.available())
  {
    String data = Serial.readString();
    std::vector<String> joint_commands = split_string(data, '-');
    if(joint_commands.size() == 5){
      int goals[5] = {
        joint_commands[0].toInt(), 
        joint_commands[1].toInt(), 
        joint_commands[2].toInt(), 
        joint_commands[3].toInt(), 
        joint_commands[4].toInt()
        };
      Servo motors[] = {joint_1, joint_2, joint_3, joint_4, joint_5};
      reach_goal(motors, goals, 1);

      // reach_goal(joint_1, joint_commands[0].toInt());
      // reach_goal(joint_2, joint_commands[1].toInt());
      // reach_goal(joint_3, joint_commands[2].toInt());
      // reach_goal(joint_4, joint_commands[3].toInt());
      // reach_goal(joint_5, joint_commands[4].toInt());
    }
  }
}

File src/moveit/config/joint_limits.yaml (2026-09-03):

# joint_limits.yaml allows the dynamics properties specified in the URDF to be overwritten or augmented as needed

# For beginners, we downscale velocity and acceleration limits.
# You can always specify higher scaling factors (<= 1.0) in your motion requests.  # Increase the values below to 1.0 to always move at maximum speed.
default_velocity_scaling_factor: 0.1
default_acceleration_scaling_factor: 0.1

# Specific joint properties can be changed with the keys [max_position, min_position, max_velocity, max_acceleration]
# Joint limits can be turned off with [has_velocity_limits, has_acceleration_limits]
joint_limits:
  joint_1:
    has_velocity_limits: true
    max_velocity: 10.0
    has_acceleration_limits: true
    max_acceleration: 6.0
  joint_2:
    has_velocity_limits: true
    max_velocity: 10.0
    has_acceleration_limits: true
    max_acceleration: 6.0
  joint_3:
    has_velocity_limits: true
    max_velocity: 10.0
    has_acceleration_limits: true
    max_acceleration: 6.0
  joint_4:
    has_velocity_limits: true
    max_velocity: 10.0
    has_acceleration_limits: true
    max_acceleration: 6.0
  joint_5:
    has_velocity_limits: true
    max_velocity: 10.0
    has_acceleration_limits: true
    max_acceleration: 6.0
  joint_6:
    has_velocity_limits: true
    max_velocity: 10.0
    has_acceleration_limits: true
    max_acceleration: 6.0

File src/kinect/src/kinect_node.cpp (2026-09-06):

// Standalone driver for the Kinect v1 (Xbox 360, model 1414).
//
// Deliberately independent of the rest of DAST-1: it depends only on rclcpp,
// sensor_msgs and libfreenect, and is not launched by sim_robot/run_robot. Its
// job is to prove the sensor reaches ROS 2, nothing more.
//
// To run:
// ros2 launch kinect kinect.launch.py
// ros2 topic hz /kinect/rgb/image_raw

#include <algorithm>
#include <chrono>
#include <cmath>
#include <cstdint>
#include <cstring>
#include <limits>
#include <string>
#include <thread>
#include <vector>

extern "C"
{
#include <libfreenect.h>
#include <libfreenect_sync.h>
}

#include "ament_index_cpp/get_package_share_path.hpp"
#include "camera_calibration_parsers/parse.hpp"
#include "rclcpp/rclcpp.hpp"
#include "sensor_msgs/msg/camera_info.hpp"
#include "sensor_msgs/msg/image.hpp"
#include "sensor_msgs/msg/point_cloud2.hpp"
#include "sensor_msgs/point_cloud2_iterator.hpp"

namespace
{
// FREENECT_RESOLUTION_MEDIUM, the only resolution the sync API exposes by default.
constexpr uint32_t kWidth = 640;
constexpr uint32_t kHeight = 480;

// Nominal VGA intrinsics for a Kinect v1, used only as a fallback when
// camera_info_url names no readable calibration. The measured intrinsics for
// this unit live in config/kinect_rgb.yaml.
constexpr double kFx = 525.0;
constexpr double kFy = 525.0;
constexpr double kCx = 319.5;
constexpr double kCy = 239.5;

// The tilt motor's usable travel; libfreenect refuses anything beyond this.
constexpr int kTiltMinDegrees = -30;
constexpr int kTiltMaxDegrees = 30;

// How long to wait for the motor to stop before reading back where it landed.
constexpr auto kTiltSettleTimeout = std::chrono::seconds(3);

// Allowed gap between the commanded angle and what the accelerometer reads.
// Wider than the motor's ~1 degree repeatability, narrow enough to catch a stall.
constexpr double kTiltToleranceDegrees = 3.0;

// Fixed-point iterations used to invert the plumb_bob distortion model. It
// converges in a handful, and this runs once per pixel at startup rather than
// once per point per frame.
constexpr int kUndistortIterations = 20;
}  // namespace

namespace kinect
{

class KinectNode : public rclcpp::Node
{
public:
  KinectNode()
  : Node("kinect")
  {
    frame_id_ = declare_parameter("frame_id", "kinect_rgb_optical_frame");
    device_index_ = declare_parameter("device_index", 0);
    publish_pointcloud_ = declare_parameter("publish_pointcloud", true);
    const double rate = declare_parameter("rate", 30.0);
    open_attempts_ = static_cast<size_t>(declare_parameter("open_attempts", 30));
    camera_info_url_ = declare_parameter(
      "camera_info_url", "package://kinect/config/kinect_rgb.yaml");
    // The point cloud is metric, but the DAST-1 model is not: its meshes are
    // millimetres scaled by 0.01, so one unit in that URDF is a decimetre. Set
    // this to 10.0 when publishing into that world; leave it at 1.0 for true
    // metres. Only the cloud is scaled -- the depth image stays SI millimetres.
    point_scale_ = declare_parameter("point_scale", 1.0);
    set_tilt_ = declare_parameter("set_tilt", true);
    tilt_degrees_ = static_cast<int>(declare_parameter("tilt_degrees", -16));

    // Default (reliable) QoS on purpose: a reliable publisher satisfies both
    // reliable and best-effort subscribers, so RViz and rqt_image_view both see
    // these topics without anyone touching QoS settings.
    rgb_pub_ = create_publisher<sensor_msgs::msg::Image>("~/rgb/image_raw", 10);
    rgb_info_pub_ = create_publisher<sensor_msgs::msg::CameraInfo>("~/rgb/camera_info", 10);
    depth_pub_ = create_publisher<sensor_msgs::msg::Image>("~/depth/image_raw", 10);
    depth_info_pub_ = create_publisher<sensor_msgs::msg::CameraInfo>("~/depth/camera_info", 10);
    cloud_pub_ = create_publisher<sensor_msgs::msg::PointCloud2>("~/points", 10);

    loadCameraInfo();
    buildUnprojectionTable();
    applyTilt();

    timer_ = create_wall_timer(
      std::chrono::duration<double>(1.0 / rate),
      std::bind(&KinectNode::tick, this));

    RCLCPP_INFO(get_logger(), "Kinect node started on device %d.", device_index_);
  }

  ~KinectNode() override
  {
    // Stops the streams and closes the device; without it the Kinect is left
    // running and the next start fails to open it.
    freenect_sync_stop();
  }

private:
  sensor_msgs::msg::CameraInfo nominalCameraInfo() const
  {
    sensor_msgs::msg::CameraInfo info;
    info.width = kWidth;
    info.height = kHeight;
    info.distortion_model = "plumb_bob";
    info.d.assign(5, 0.0);
    info.k = {kFx, 0.0, kCx, 0.0, kFy, kCy, 0.0, 0.0, 1.0};
    info.r = {1.0, 0.0, 0.0, 0.0, 1.0, 0.0, 0.0, 0.0, 1.0};
    info.p = {kFx, 0.0, kCx, 0.0, 0.0, kFy, kCy, 0.0, 0.0, 0.0, 1.0, 0.0};
    return info;
  }

  // Resolves the package:// and file:// forms camera_info_url can take, so a
  // recalibration is a file edit and a restart, never a rebuild.
  std::string resolveUrl(const std::string & url) const
  {
    static constexpr char kPackagePrefix[] = "package://";
    static constexpr char kFilePrefix[] = "file://";

    if (url.rfind(kFilePrefix, 0) == 0) {
      return url.substr(std::strlen(kFilePrefix));
    }
    if (url.rfind(kPackagePrefix, 0) != 0) {
      return url;  // already a plain path
    }

    const std::string rest = url.substr(std::strlen(kPackagePrefix));
    const size_t slash = rest.find('/');
    if (slash == std::string::npos) {
      return {};
    }

    try {
      return (ament_index_cpp::get_package_share_path(rest.substr(0, slash)) /
             rest.substr(slash + 1)).string();
    } catch (const std::exception & e) {
      RCLCPP_ERROR(get_logger(), "Cannot resolve '%s': %s", url.c_str(), e.what());
      return {};
    }
  }

  void loadCameraInfo()
  {
    camera_info_ = nominalCameraInfo();

    const std::string path = resolveUrl(camera_info_url_);
    std::string camera_name;
    sensor_msgs::msg::CameraInfo loaded;

    if (path.empty() ||
      !camera_calibration_parsers::readCalibration(path, camera_name, loaded))
    {
      RCLCPP_WARN(
        get_logger(),
        "No calibration read from '%s'; falling back to nominal Kinect v1 "
        "intrinsics. Cloud geometry will be approximate.",
        camera_info_url_.c_str());
      return;
    }

    // A calibration taken at another resolution would misplace every point
    // silently, and this driver only ever streams VGA.
    if (loaded.width != kWidth || loaded.height != kHeight) {
      RCLCPP_ERROR(
        get_logger(),
        "Calibration '%s' is %ux%u but the Kinect streams %ux%u; ignoring it.",
        path.c_str(), loaded.width, loaded.height, kWidth, kHeight);
      return;
    }

    camera_info_ = loaded;
    RCLCPP_INFO(
      get_logger(),
      "Loaded calibration '%s' from %s (fx=%.2f fy=%.2f cx=%.2f cy=%.2f).",
      camera_name.c_str(), path.c_str(),
      camera_info_.k[0], camera_info_.k[4], camera_info_.k[2], camera_info_.k[5]);
  }
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

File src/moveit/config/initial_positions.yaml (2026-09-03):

# Default initial positions for dast_1's ros2_control fake system

initial_positions:
  joint_1: 0
  joint_2: 0
  joint_3: 0
  joint_4: 0
  joint_5: 0
  joint_6: 0

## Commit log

2024-12-24 Add URDF description file and stl parts
    [arm_1.stl, arm_2.stl, arm_3.stl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]
2024-12-24 bare minimum to display the urdf model
2024-12-24 add all links and joints to urdf. add stl files for collision
    [arm_1_collision.stl, arm_2_collision.stl, arm_3_collision.stl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]
2024-12-25 add controller
    [control.xacro, controller.yaml, description.urdf.xacro]
2024-12-26 add moveit launch and configs
    [description.urdf.xacro, joint_limits.yaml]
2024-12-29 refactor kinematics yml. improve interface_pose. works now.
2024-12-30 add virtual joint for tip
    [description.urdf.xacro]
2025-01-03 add virtual_joints to srdf. update ctrl freq. resulted from plan visualization attempts.
    [controller.yaml]
2025-01-05 attempts to use joint values and fw kinematics to build the reachable workspace
2025-01-29 add nodes for serial comm. add arduino code for moving servo by serial command.
2025-02-03 modify controller for real robot. servos move but one by one.
    [control.xacro, controller.yaml, description.urdf.xacro]
2025-02-14 attempts to make the task_server_angle read from yaml. did not work. probably not possible with node as plugin.
    [control.xacro, controller.yaml]
2025-02-15 update firmware command to handle negatives. update urdfs.
    [base.stl, base_collision.stl, description.urdf.xacro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]
2025-03-10 modify to match latest mechanics. define better home position
    [controller.yaml, description.urdf.xacro]
2025-03-16 add mechancal details
    [arm_1_body.stl, arm_2_bearing_shaft.stl, arm_2_body.stl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]
2026-08-27 ported to ros lyrical
    [control.xacro, description.urdf.xacro]
2026-08-28 add interface_sequence for collision-checked multi-waypoint motion
    New CLI tool, in the same style as interface_angle and interface_pose:
    ros2 run moveit interface_sequence <waypoints.yaml>
    It reads waypoints from a YAML file and drives /sequence_move_group, so every
    segment is planned with collision checking and the whole path runs as one
    motion. Each segment takes either joints (radians) or pose (x y z r p y), plus
    a type of PTP/LIN/CIRC. See config/sequence_example.yaml for the format.
    Keep blend_radius at 0. Pilz blends by sampling Cartesian poses through the
    corner and solving IK for each one; with only 5 DOF most of those poses have
    no solution and the whole sequence dies with t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
    [sequence_example.yaml]
2026-09-03 Add temporary joint_6 for 6-DOF simulation
    A massless wrist_link and a Y-axis joint_6 make the arm 6-DOF in simulation only: no servo or mesh behind it, and the real joint will replace it. Kinematics at joint_6 = 0 are unchanged, so recorded poses still hold, and Pilz blending works again. The gripper moved to joint_7; the hardware path is deliberately left broken.
    [control.xacro, controller.yaml, description.urdf.xacro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]
2026-09-03 Add standalone kinect package for Kinect v1
    Verifies an Xbox 360 Kinect (model 1414) reaches ROS 2 before any integration work, publishing RGB, registered depth, camera info and an organised XYZRGB cloud at 30 Hz over libfreenect's sync API. Deliberately isolated from the robot launch path so a failure here points at the sensor or the driver and nothing else. The community kinect_ros2 driver was not vendored: it predates Lyrical and needs four build fixes plus a depth_image_proc dlopen hack.
    [kinect_node.cpp]
2026-09-06 Load real intrinsics and set Kinect tilt
    Intrinsics were nominal placeholders, so cloud geometry was wrong by up to 4 cm at the corners once real distortion was applied. They now load from config/kinect_rgb.yaml with distortion corrected through a startup lookup table, and the tilt motor is commanded on every start so it cannot drift away from the extrinsic calibration.
    [kinect_node.cpp]
2026-09-06 Add Kinect to the robot in both modes
    The camera now lives in the robot description, so simulation and hardware publish the same topics and MoveIt maps both into one octomap. Gazebo needs its own world file because the stock empty.sdf ne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
    [dast_1.sdf, description.urdf.xacro]
